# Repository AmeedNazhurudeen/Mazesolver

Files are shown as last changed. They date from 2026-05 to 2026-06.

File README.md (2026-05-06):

# 🐭 Micromouse Maze Solver Robot

An autonomous micromouse robot designed to solve unknown mazes using real-time mapping, flood fill path planning, and sensor-based closed-loop control.

This project focuses on **embedded robotics, motion control, and intelligent path planning under real-world constraints**.

---

## 🚀 Project Goals

- Explore unknown 16×16 maze environments
- Build an internal map in real-time
- Compute shortest path to the goal cell
- Execute high-speed optimized runs
- Maintain stable motion using PID control

---

## ⚙️ Hardware Overview

- **Microcontroller:** Teensy 2.0 (upgradeable to Teensy 4.0)
- **Motors:** N20 DC motors with encoders
- **Motor Driver:** TB6612FNG / DRV8833 (recommended upgrade)
- **Distance Sensors:** VL53L0X ToF sensors (x3)
- **IMU:** MPU6050 (gyro + accelerometer)
- **Power:** LiPo battery (7.4V recommended)

---

## 🧠 Core System Architecture

The robot is designed as a layered embedded system:

Sensors → Perception → Mapping → Decision → Motion → Control

### Layers:

- **Sensor Layer:** IR / ToF / Encoder / IMU readings
- **Perception Layer:** Wall detection & distance estimation
- **Mapping Layer:** Maze grid construction
- **Decision Layer:** Flood Fill path planning
- **Motion Layer:** Speed profile & turn execution
- **Control Layer:** PID motor control

---

## 🧭 Algorithms Used

### 1. Flood Fill Algorithm (Main Navigation)

Each maze cell is assigned a distance value relative to the goal. The robot always moves toward the lowest-cost neighboring cell.

This ensures:
- Guaranteed shortest path (after full exploration)
- Dynamic adaptation to discovered walls
- Real-time re-planning capability

---

### 2. PID Control System

Used for:
- Wall following stability
- Speed control
- Smooth turning

Inputs:
- Encoder feedback
- IR sensor error

---

### 3. State Machine

The robot operates in two main modes:

- **EXPLORATION MODE**
  - Builds maze map
  - Updates flood fill values dynamically

- **SPEED RUN MODE**
  - Executes optimized shortest path
  - Focuses on maximum speed and stability

---

## 📡 Sensor Strategy

### Primary Sensors:
- IR sensors → real-time wall detection (fast control loop)

### Secondary Sensors:
- VL53L0X ToF → distance estimation & mapping support
- MPU6050 IMU → turning stability and angular correction
- Encoders → precise movement tracking

---

## ⚡ Motion Strategy

- Trapezoidal velocity profile (accelerate → cruise → decelerate)
- Corner smoothing for faster turns
- Straight-line optimization during speed run phase

---

## 🧱 Key Features

- Real-time maze mapping
- Adaptive flood fill path planning
- Sensor fusion-based navigation
- Closed-loop PID motor control
- Exploration + speed run mode switching

---

## 🛠️ Folder Structure

micromouse-maze-solver/
│
├── firmware/ # Embedded robot code
├── hardware/ # PCB, wiring, BOM
├── simulation/ # Maze simulation tools
├── docs/ # Architecture & technical docs
├── tools/ # Calibration & debugging scripts
└── tests/ # Unit tests for algorithms

---

## 📈 Future Improvements

- Upgrade to high-speed microcontroller (Teensy 4.0 / STM32)
- Replace or complement ToF with high-speed IR arrays
- Implement A* hybrid optimization for faster path computation
- Add SLAM-based mapping for advanced research applications
- Improve motion planning using S-curve velocity profiles

---

## 🎯 Applications

- Micromouse robotics competitions
- Autonomous navigation research
- Embedded systems optimization
- Path planning algorithm benchmarking
- Mobile robotics research projects

---

## 🧪 Status

🚧 In Development  
✔ Hardware design ongoing  
✔ Algorithm implementation in progress  
✔ Simulation layer planned  

---

## 📜 License

This project is open-source for educational and research purposes.

---

## 🤖 Author

Built as part of an advanced robotics learning and competition project focused on autonomous navigation systems and embedded intelligence.

---

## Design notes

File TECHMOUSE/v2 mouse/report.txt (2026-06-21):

Info: Output directory '/Users/ameednazhurudeen/Downloads/SONIC MOUSE V3' created.
Plotted to '/Users/ameednazhurudeen/Downloads/SONIC MOUSE V3/v2 mouse-F_Cu.gbr'.
Plotted to '/Users/ameednazhurudeen/Downloads/SONIC MOUSE V3/v2 mouse-B_Cu.gbr'.
Plotted to '/Users/ameednazhurudeen/Downloads/SONIC MOUSE V3/v2 mouse-F_Silkscreen.gbr'.
Plotted to '/Users/ameednazhurudeen/Downloads/SONIC MOUSE V3/v2 mouse-B_Silkscreen.gbr'.
Plotted to '/Users/ameednazhurudeen/Downloads/SONIC MOUSE V3/v2 mouse-F_Mask.gbr'.
Plotted to '/Users/ameednazhurudeen/Downloads/SONIC MOUSE V3/v2 mouse-B_Mask.gbr'.
Plotted to '/Users/ameednazhurudeen/Downloads/SONIC MOUSE V3/v2 mouse-Edge_Cuts.gbr'.
Created Gerber job file '/Users/ameednazhurudeen/Downloads/SONIC MOUSE V3/v2 mouse-job.gbrjob'.
Info: Done.
Info: Done.

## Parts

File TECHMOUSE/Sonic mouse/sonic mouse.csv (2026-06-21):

Reference | Qty | Value | DNP | Exclude from BOM | Exclude from Board | Footprint | Datasheet
ACC1 | 1 | GY-521 |  |  |  | GY-521:GY-521
C1,C2,C3,C4,C5,C6 | 6 | EEUFR1E101 |  |  |  | EEUFR1E101:CAPPRD250W50D630H1120
C7,C9 | 2 | C_Small |  |  |  | ceramic:C320C | ~
D1 | 1 | LED |  |  |  | LED_THT:LED_D3.0mm_Horizontal_O1.27mm_Z6.0mm | ~
D3 | 1 | LED D2 |  |  |  | LED_THT:LED_D3.0mm_Horizontal_O1.27mm_Z6.0mm | ~
J1 | 1 | B2B-XH-A_LF__SN_ |  |  |  | Connector_JST:JST_EH_B2B-EH-A_1x02_P2.50mm_Vertical
J2 | 1 | Motor 1 |  |  |  | Connector_JST:JST_PH_B2B-PH-K_1x02_P2.00mm_Vertical
J3 | 1 | Motor 2 |  |  |  | Connector_JST:JST_PH_B2B-PH-K_1x02_P2.00mm_Vertical
J4 | 1 | Conn_01x06_Socket |  |  |  | Connector_PinSocket_1.27mm:PinSocket_1x06_P1.27mm_Vertical | ~
R1,R2,R3,R4 | 4 | 220 |  |  |  | Resistor_THT:R_Axial_DIN0204_L3.6mm_D1.6mm_P1.90mm_Vertical | ~
R5,R6,R7,R11 | 4 | 10 |  |  |  | Resistor_THT:R_Axial_DIN0204_L3.6mm_D1.6mm_P1.90mm_Vertical | ~
R9,R10 | 2 | 330 |  |  |  | Resistor_THT:R_Axial_DIN0204_L3.6mm_D1.6mm_P1.90mm_Vertical | ~
S1,S2 | 2 | FSM8JH |  |  |  | FSM8JH:SW_FSM8JH
U1 | 1 | AMS1117-5.0 |  |  |  | AMS1117-5.0:SOT229P700X180-4N
U2 | 1 | AMS1117-3.3 |  |  |  | AMS1117-3.3:SOT229P700X180-4N
U3 | 1 | DEV-15583 |  |  |  | DEV-15583 (2):MODULE_DEV-15583
U4 | 1 | ROB-14450 |  |  |  | ROB-14450:MODULE_ROB-14450
U5,U6,U7,U8 | 4 | TCRT5000 |  |  |  | TCRT5000 (1):OPTO_TCRT5000

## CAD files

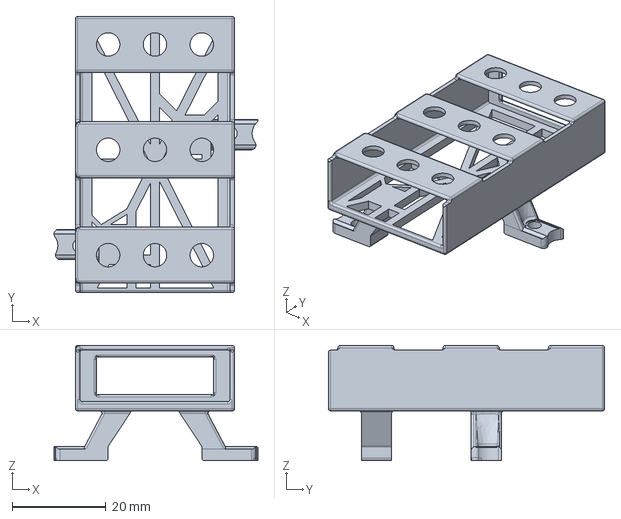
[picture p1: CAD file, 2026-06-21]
design files/Battery holder.step
43.6 x 59.0 x 24.6 mm

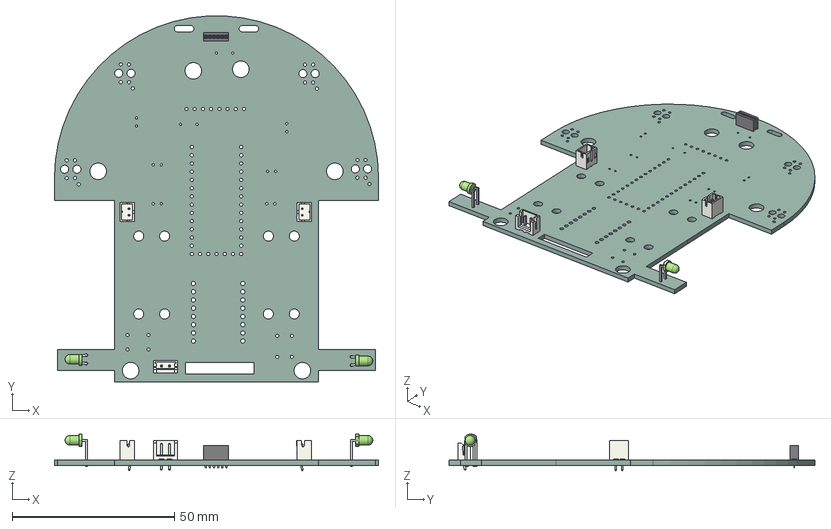
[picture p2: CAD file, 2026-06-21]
TECHMOUSE/v2 mouse/v2 mouse.step
100.0 x 112.9 x 11.3 mm
LED_D3.0mm_Horizontal_O1.27mm_Z6.0mm x 2
PinSocket_1x06_P1.27mm_Vertical
JST_EH_B2B-EH-A_1x02_P2.50mm_Vertical
JST_PH_B2B-PH-K_1x02_P2.00mm_Vertical x 2
v2 mouse_PCB

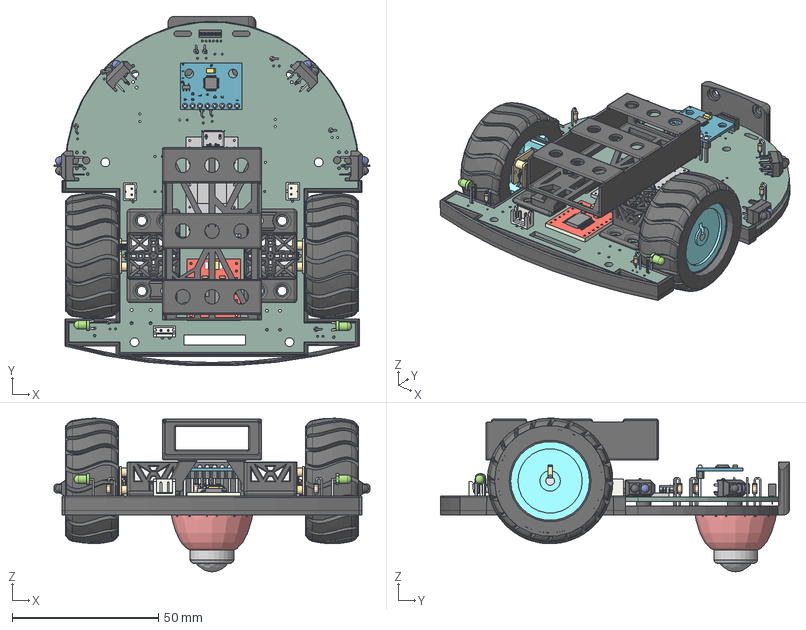
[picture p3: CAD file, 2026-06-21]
design files/Maze Solver .step
108.1 x 119.5 x 52.6 mm
R_Axial_DIN0204_L3.6mm_D1.6mm_P1.90mm_Vertical x 10
LED_D3.0mm_Horizontal_O1.27mm_Z6.0mm x 2
PinSocket_1x06_P1.27mm_Vertical
JST_EH_B2B-EH-A_1x02_P2.50mm_Vertical
JST_PH_B2B-PH-K_1x02_P2.00mm_Vertical x 2
v2 mouse_PCB
clamp x 2
Teensy_4.0_PCB
Micro USB-B Female 5Pin SMD
NXP iMXRT1062
SKRPACE010 v4
TB6612FNG_No Pins
Gear Box x 2
Shaft x 2
Motor x 2
Y
Clone_of_Array
Clone_of_Clone_of_Array
Clone_of_Clone_of_Array001
VCC
GND
SCL
SDA
XDA
XCL
AD0
INT
BotNakama
MPU_1
Cubo001
X
TCRT-5000-modelado x 2
TCRT-5000-modelado v1(Mirror) x 2
Housing x 2
Ball Caster Wheel

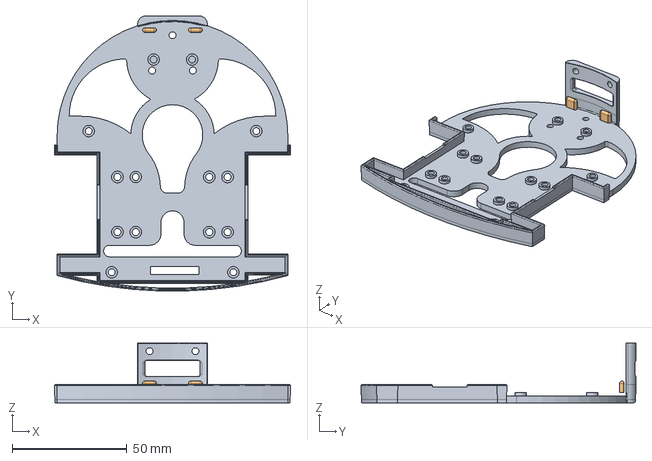
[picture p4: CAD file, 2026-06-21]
design files/Base Frame.step
102.8 x 119.8 x 26.0 mm

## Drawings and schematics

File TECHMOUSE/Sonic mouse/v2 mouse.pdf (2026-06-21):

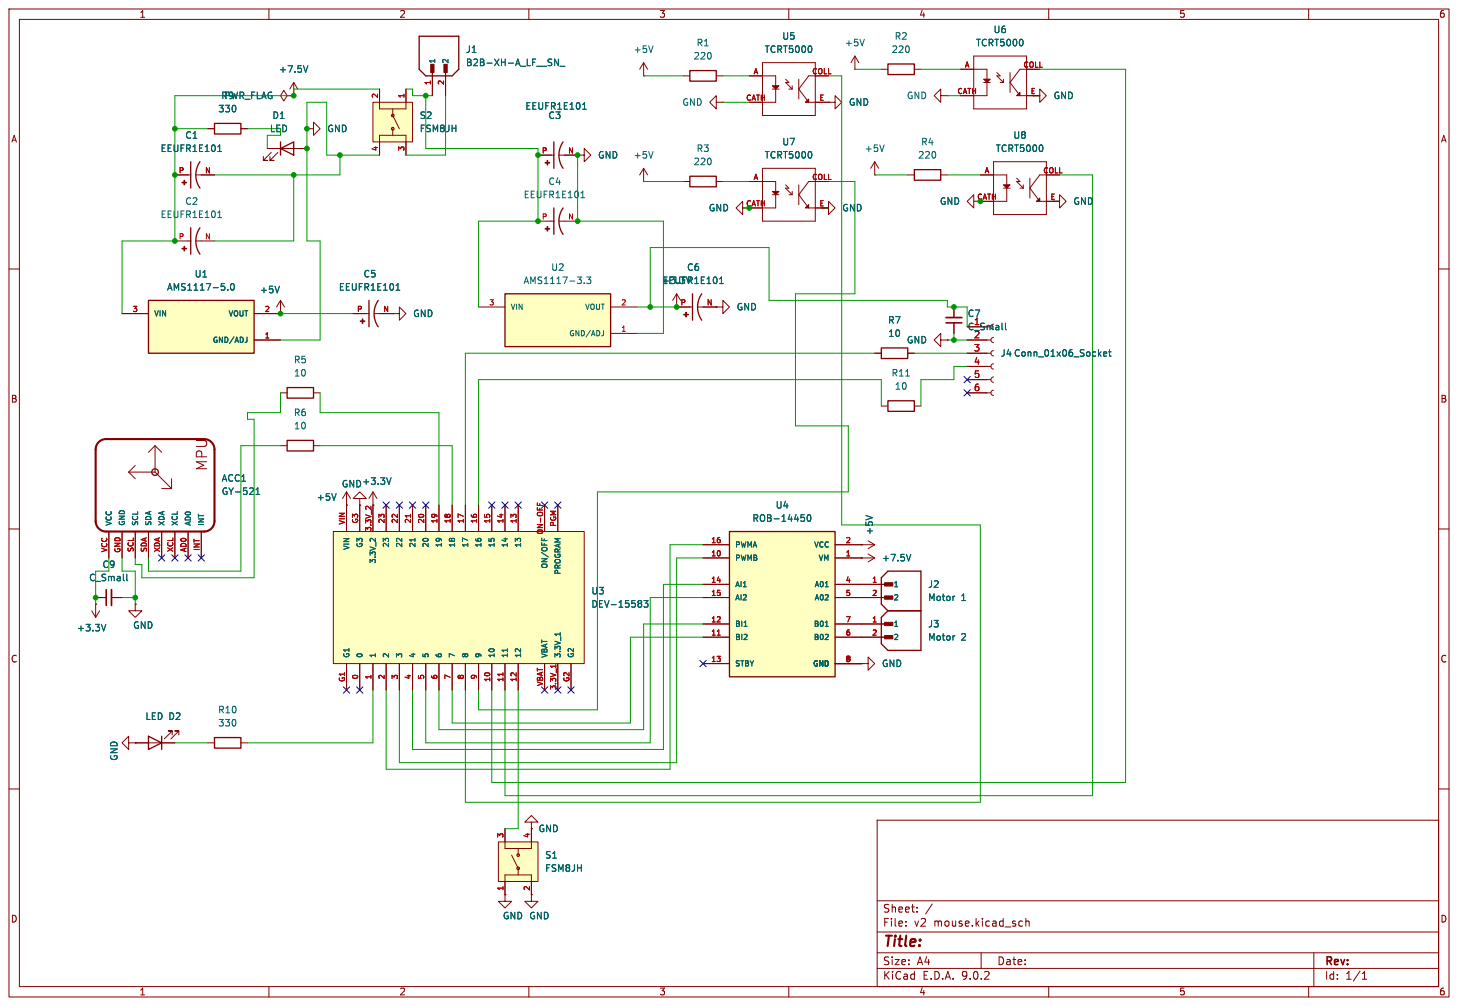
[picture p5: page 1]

9 10 10 11 11 12 12 VBAT VBAT 3.3V_1 3.3V_1 G2 G2 VIN VIN G3 G3 3.3V_2 3.3V_2 23 23 22 22 21 21 20 20 19 19 18 18 17 17 16 16 15 15 14 14 13 13 ON/OFF ON-OFF PROGRAM PGM U3 DEV-15583

9 10 10 11 11 12 12 VBAT VBAT 3.3V_1 3.3V_1 G2 G2 VIN VIN G3 G3 3.3V_2 3.3V_2 23 23 22 22 21 21 20 20 19 19 18 18 17 17 16 16 15 15 14 14 13 13 ON/OFF ON-OFF PROGRAM PGM GNDGND GND

Id: 1/1 Title: File: v2 mouse.kicad_sch Sheet: /

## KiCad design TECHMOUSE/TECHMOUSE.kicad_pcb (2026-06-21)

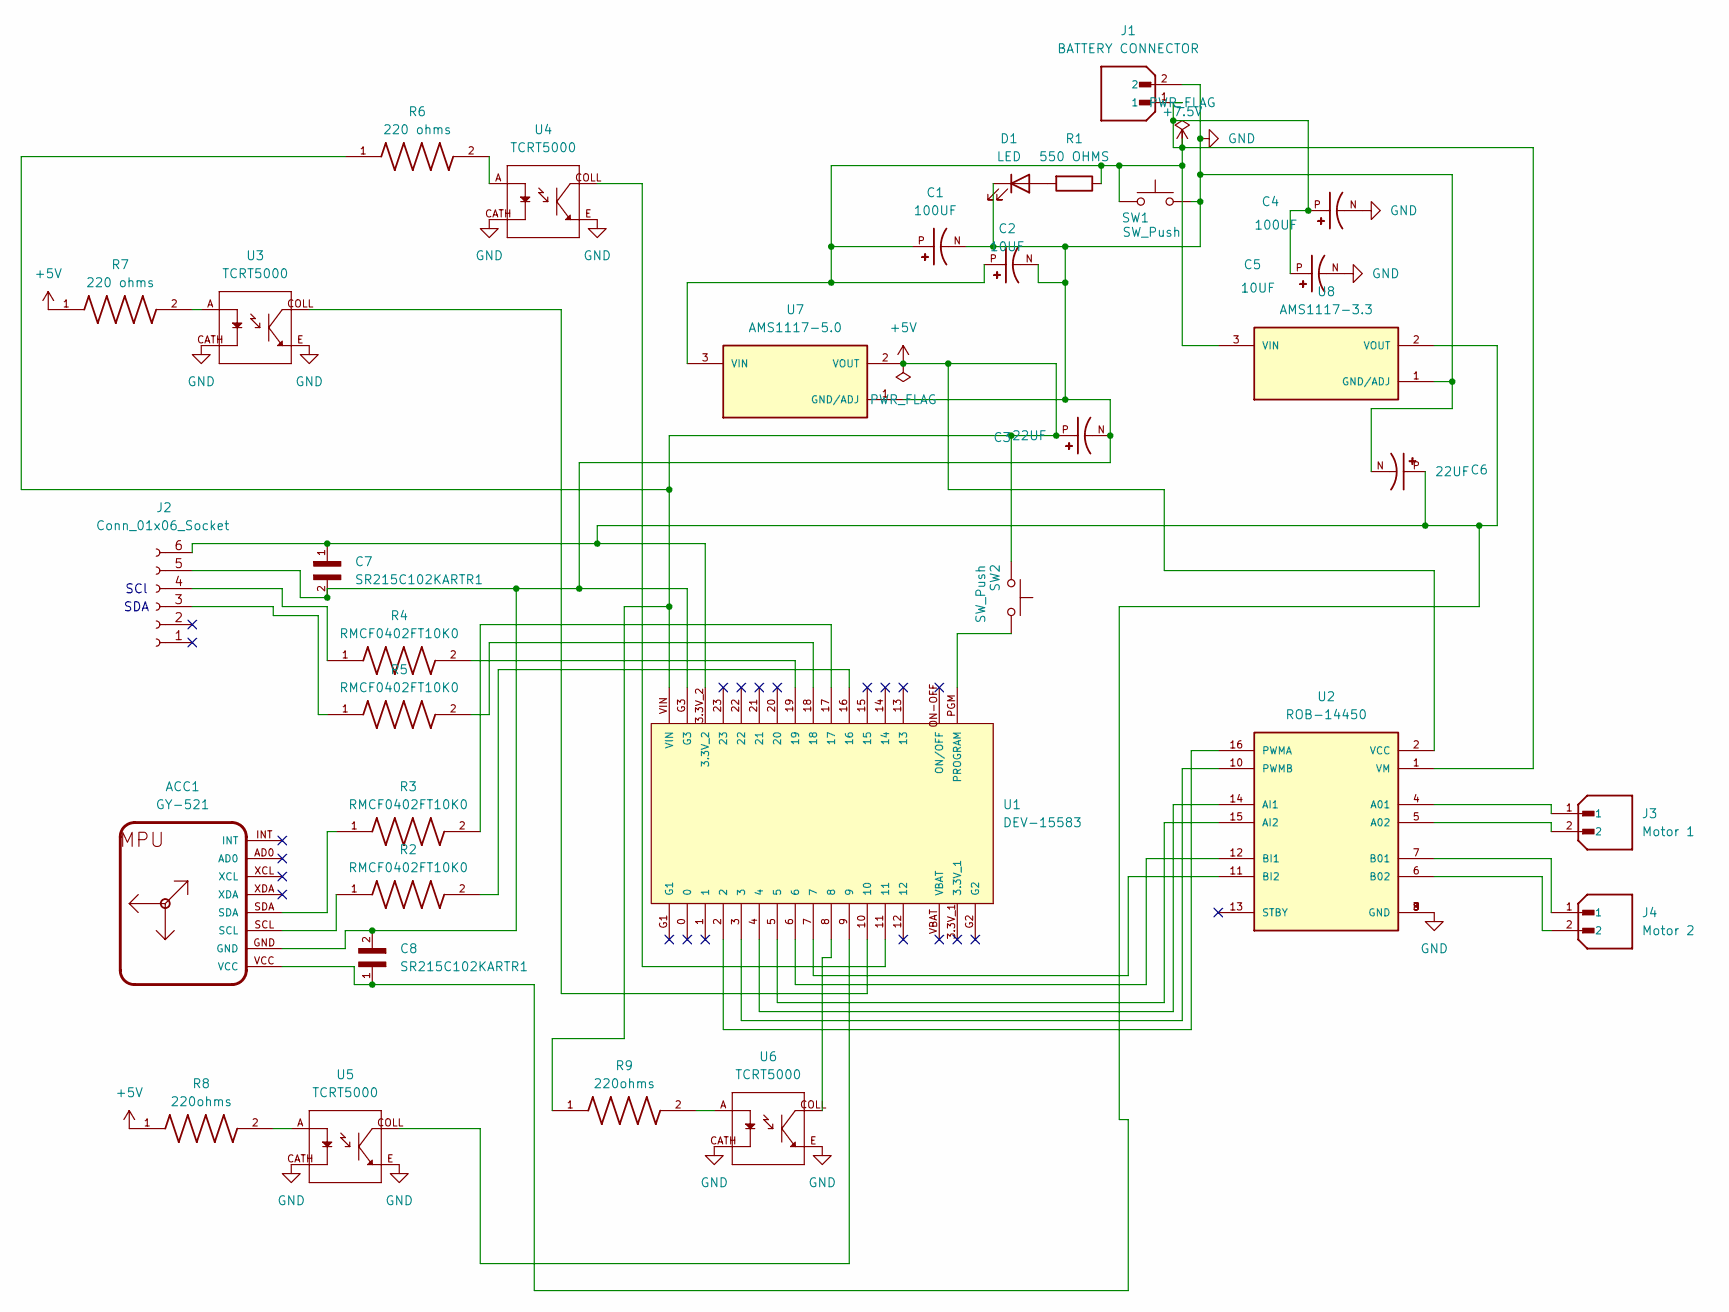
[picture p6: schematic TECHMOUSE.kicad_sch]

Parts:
ACC1: GY-521
C1, C4: 100UF; CAPPRD250W50D630H1120; PARTREV 28-FEB-20
C2, C5: 10UF; CAPPRD250W50D630H1120; PARTREV 28-FEB-20
C3, C6: 22UF; CAPPRD250W50D630H1120; PARTREV 28-FEB-20
C7, C8: SR215C102KARTR1; CAPRR508W50L508T317H508; PARTREV 081816
D1: LED; LED_D1.8mm_W1.8mm_H2.4mm_Horizontal_O1.27mm_Z8.2mm
J1: BATTERY CONNECTOR; JST_EH_B2B-EH-A_1x02_P2.50mm_Vertical; PARTREV N/A
J2: Conn_01x06_Socket; PinSocket_1x06_P1.27mm_Vertical
J3: Motor 1; JST_EH_B2B-EH-A_1x02_P2.50mm_Vertical; PARTREV N/A
J4: Motor 2; JST_EH_B2B-EH-A_1x02_P2.50mm_Vertical; PARTREV N/A
R1: 550 OHMS; R_Axial_DIN0204_L3.6mm_D1.6mm_P5.08mm_Horizontal
R2, R3, R4, R5: RMCF0402FT10K0; RESC1005X40
R6, R7: 220 ohms; RESC1005X35N
R8, R9: 220ohms; RESC1005X35N
SW1, SW2: SW_Push; SW_PUSH_6mm
U1: DEV-15583; MODULE_DEV-15583
U2: ROB-14450; MODULE_ROB-14450; PARTREV 11-13-17
U3, U4, U5, U6: TCRT5000; OPTO_TCRT5000; PARTREV 1.7
U7: AMS1117-5.0; SOT229P700X180-4N; PARTREV N/A
U8: AMS1117-3.3; SOT229P700X180-4N; PARTREV N/A

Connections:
+5V: C3.P, R6.1, R7.1, R8.1, R9.1, SW2.1, U1.VIN, U2.2 (VCC), U7.2 (VOUT)
+7.5V: C1.P, C2.P, C4.P, C5.P, J1.1, R1.1, SW1.1, U2.1 (VM), U7.3 (VIN), U8.3 (VIN)
GND: ACC1.GND, C1.N, C2.N, C3.N, C4.N, C5.N, C6.N, C7.2, C8.2, D1.1 (K), J1.2, J2.5, SW1.2, U1.G3, U2.3 (GND), U2.8 (GND), U2.9 (GND), U3.CATH, U3.E, U4.CATH, U4.E, U5.CATH, U5.E, U6.CATH, U6.E, U7.1 (GND/ADJ), U8.1 (GND/ADJ)
unnamed: ACC1.SCL, R2.1
unnamed: ACC1.SDA, R3.1
unnamed: D1.2 (A), R1.2
unnamed: J2.3, R5.1
unnamed: J2.4, R4.1
unnamed: ACC1.VCC, C6.P, C7.1, C8.1, J2.6, U1.3.3V_2, U8.2 (VOUT)
unnamed: R2.2, U1.16
unnamed: R3.2, U1.17
unnamed: R4.2, U1.19
unnamed: R5.2, U1.18
unnamed: R6.2, U4.A
unnamed: R7.2, U3.A
unnamed: R8.2, U5.A
unnamed: R9.2, U6.A
unnamed: SW2.2, U1.PGM (PROGRAM)
unnamed: U1.8, U6.COLL
unnamed: U1.9, U5.COLL
unnamed: U1.10, U3.COLL
unnamed: U1.11, U4.COLL
unnamed: J3.1, U2.4 (A01)
unnamed: J3.2, U2.5 (A02)
unnamed: U1.4, U2.14 (AI1)
unnamed: U1.5, U2.15 (AI2)
unnamed: J4.1, U2.7 (B01)
unnamed: J4.2, U2.6 (B02)
unnamed: U1.6, U2.12 (BI1)
unnamed: U1.7, U2.11 (BI2)
unnamed: U1.2, U2.16 (PWMA)
unnamed: U1.3, U2.10 (PWMB)

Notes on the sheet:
SDA
SCl

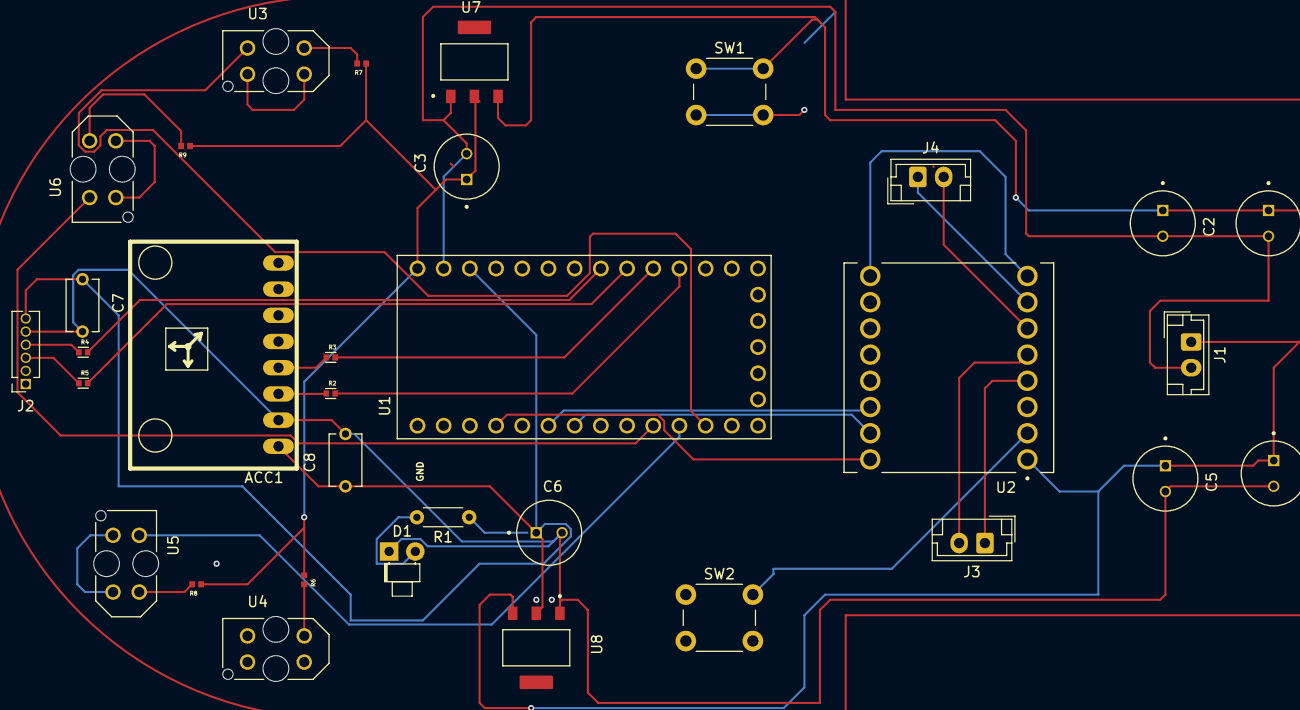
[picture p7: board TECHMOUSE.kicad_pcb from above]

Board: 2 copper layers, 33 parts (0 on the bottom side), 32 nets.

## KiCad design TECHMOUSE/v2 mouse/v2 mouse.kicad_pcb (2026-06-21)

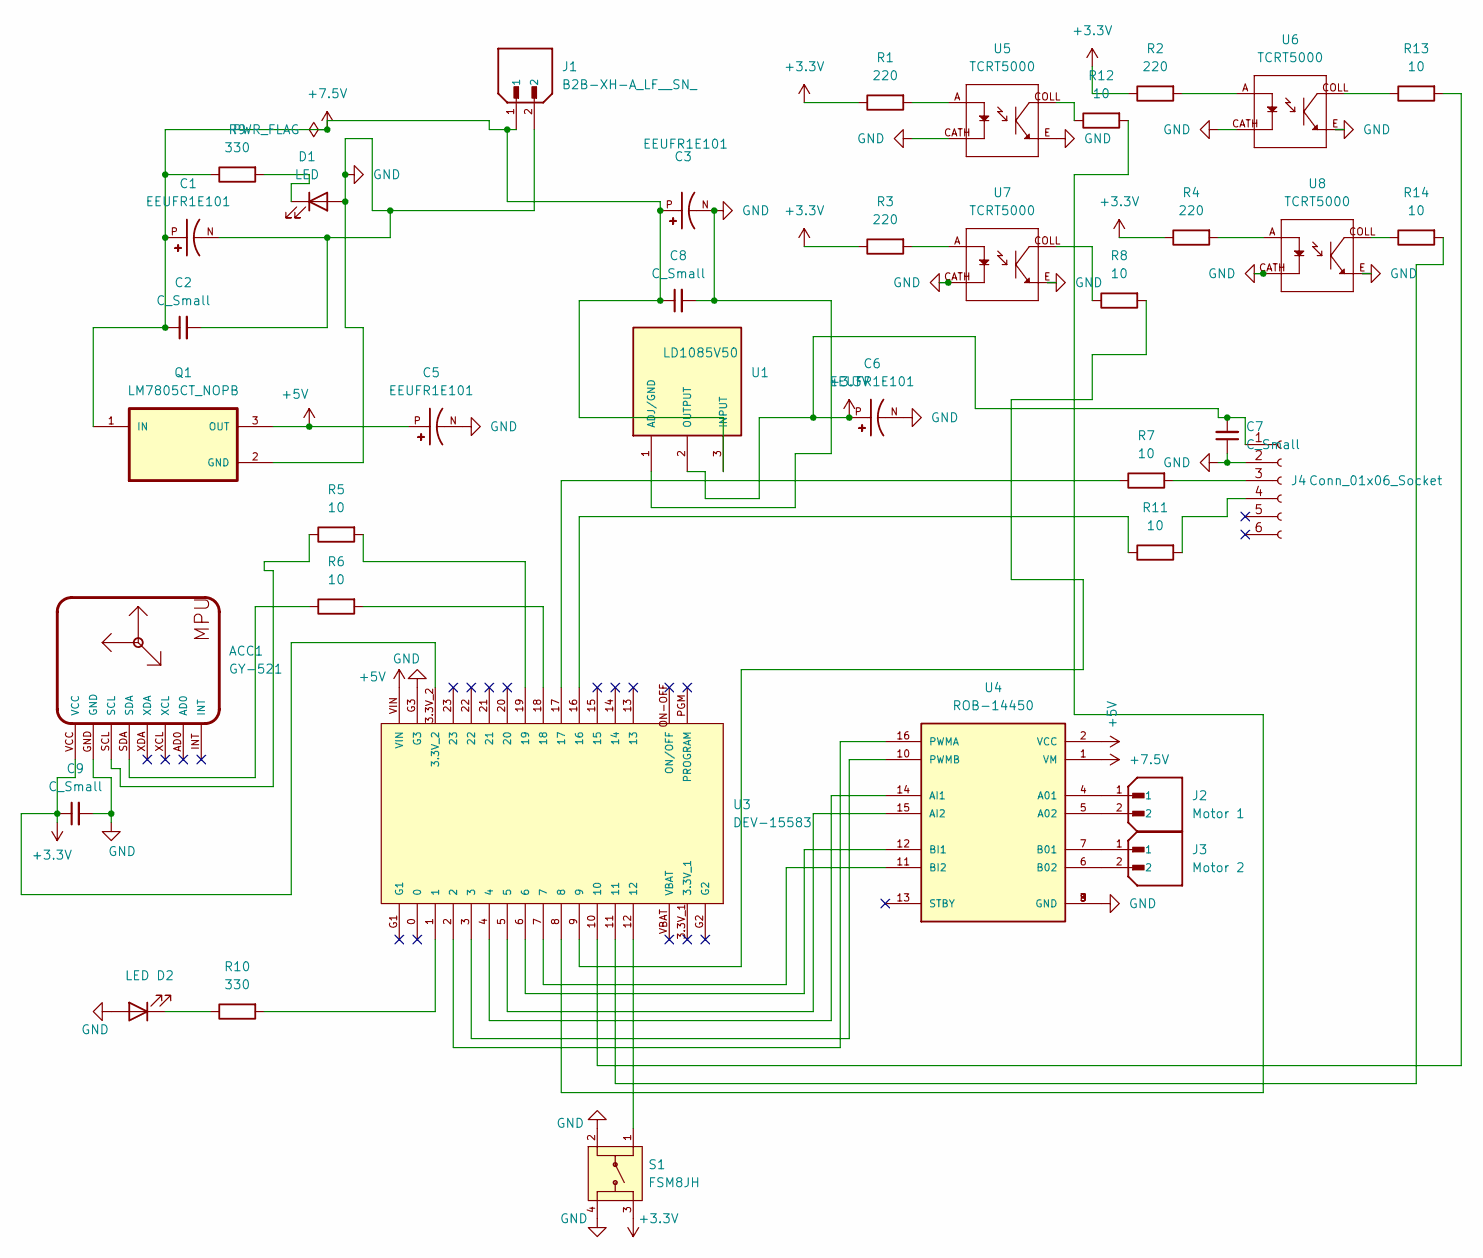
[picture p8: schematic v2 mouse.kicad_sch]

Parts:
ACC1: GY-521
C1, C3, C5, C6: EEUFR1E101; CAPPRD250W50D630H1120; PARTREV 28-FEB-20
C2, C7, C8, C9: C_Small; C320C
D1: LED; LED_D3.0mm_Horizontal_O1.27mm_Z6.0mm
D3: LED D2; LED_D3.0mm_Horizontal_O1.27mm_Z6.0mm
J1: B2B-XH-A_LF__SN_; JST_EH_B2B-EH-A_1x02_P2.50mm_Vertical; PARTREV N/A
J2: Motor 1; JST_PH_B2B-PH-K_1x02_P2.00mm_Vertical; PARTREV N/A
J3: Motor 2; JST_PH_B2B-PH-K_1x02_P2.00mm_Vertical; PARTREV N/A
J4: Conn_01x06_Socket; PinSocket_1x06_P1.27mm_Vertical
Q1: LM7805CT_NOPB; TO220; PARTREV LTR
R1, R2, R3, R4: 220; R_Axial_DIN0204_L3.6mm_D1.6mm_P1.90mm_Vertical
R5, R6, R7, R8, R11, R12, R13, R14: 10; R_Axial_DIN0204_L3.6mm_D1.6mm_P1.90mm_Vertical
R9, R10: 330; R_Axial_DIN0204_L3.6mm_D1.6mm_P1.90mm_Vertical
S1: FSM8JH; SW_FSM8JH; PARTREV C10
U1: LD1085V50; TO220
U3: DEV-15583; MODULE_DEV-15583
U4: ROB-14450; MODULE_ROB-14450; PARTREV 11-13-17
U5, U6, U7, U8: TCRT5000; OPTO_TCRT5000; PARTREV 1.7

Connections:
+3.3V: ACC1.VCC, C6.P, C7.2, C9.1, J4.1, R1.1, R2.1, R3.1, R4.1, S1.3, U1.2 (OUTPUT), U3.3.3V_2
+5V: C5.P, Q1.3 (OUT), U3.VIN, U4.2 (VCC)
+7.5V: C1.P, C2.1, C3.P, C8.1, J1.1, Q1.1 (IN), R9.1, U1.3 (INPUT), U4.1 (VM)
GND: ACC1.GND, C1.N, C2.2, C3.N, C5.N, C6.N, C7.1, C8.2, C9.2, D1.2 (A), D3.2 (A), J1.2, J4.2, Q1.2 (GND), S1.2, S1.4, U1.1 (ADJ/GND), U3.G3, U4.3 (GND), U4.8 (GND), U4.9 (GND), U5.CATH, U5.E, U6.CATH, U6.E, U7.CATH, U7.E, U8.CATH, U8.E
unnamed: ACC1.SCL, R5.1
unnamed: ACC1.SDA, R6.1
unnamed: D1.1 (K), R9.2
unnamed: D3.1 (K), R10.1
unnamed: J4.3, R7.2
unnamed: J4.4, R11.2
unnamed: R1.2, U5.A
unnamed: R2.2, U6.A
unnamed: R3.2, U7.A
unnamed: R4.2, U8.A
unnamed: R5.2, U3.19
unnamed: R6.2, U3.18
unnamed: R7.1, U3.17
unnamed: R8.1, U7.COLL
unnamed: R8.2, U3.9
unnamed: R10.2, U3.1
unnamed: R11.1, U3.16
unnamed: R12.1, U5.COLL
unnamed: R12.2, U3.8
unnamed: R13.1, U6.COLL
unnamed: R13.2, U3.10
unnamed: R14.1, U8.COLL
unnamed: R14.2, U3.11
unnamed: S1.1, U3.12
unnamed: J2.1, U4.4 (A01)
unnamed: J2.2, U4.5 (A02)
unnamed: U3.4, U4.14 (AI1)
unnamed: U3.5, U4.15 (AI2)
unnamed: J3.1, U4.7 (B01)
unnamed: J3.2, U4.6 (B02)
unnamed: U3.6, U4.12 (BI1)
unnamed: U3.7, U4.11 (BI2)
unnamed: U3.2, U4.16 (PWMA)
unnamed: U3.3, U4.10 (PWMB)

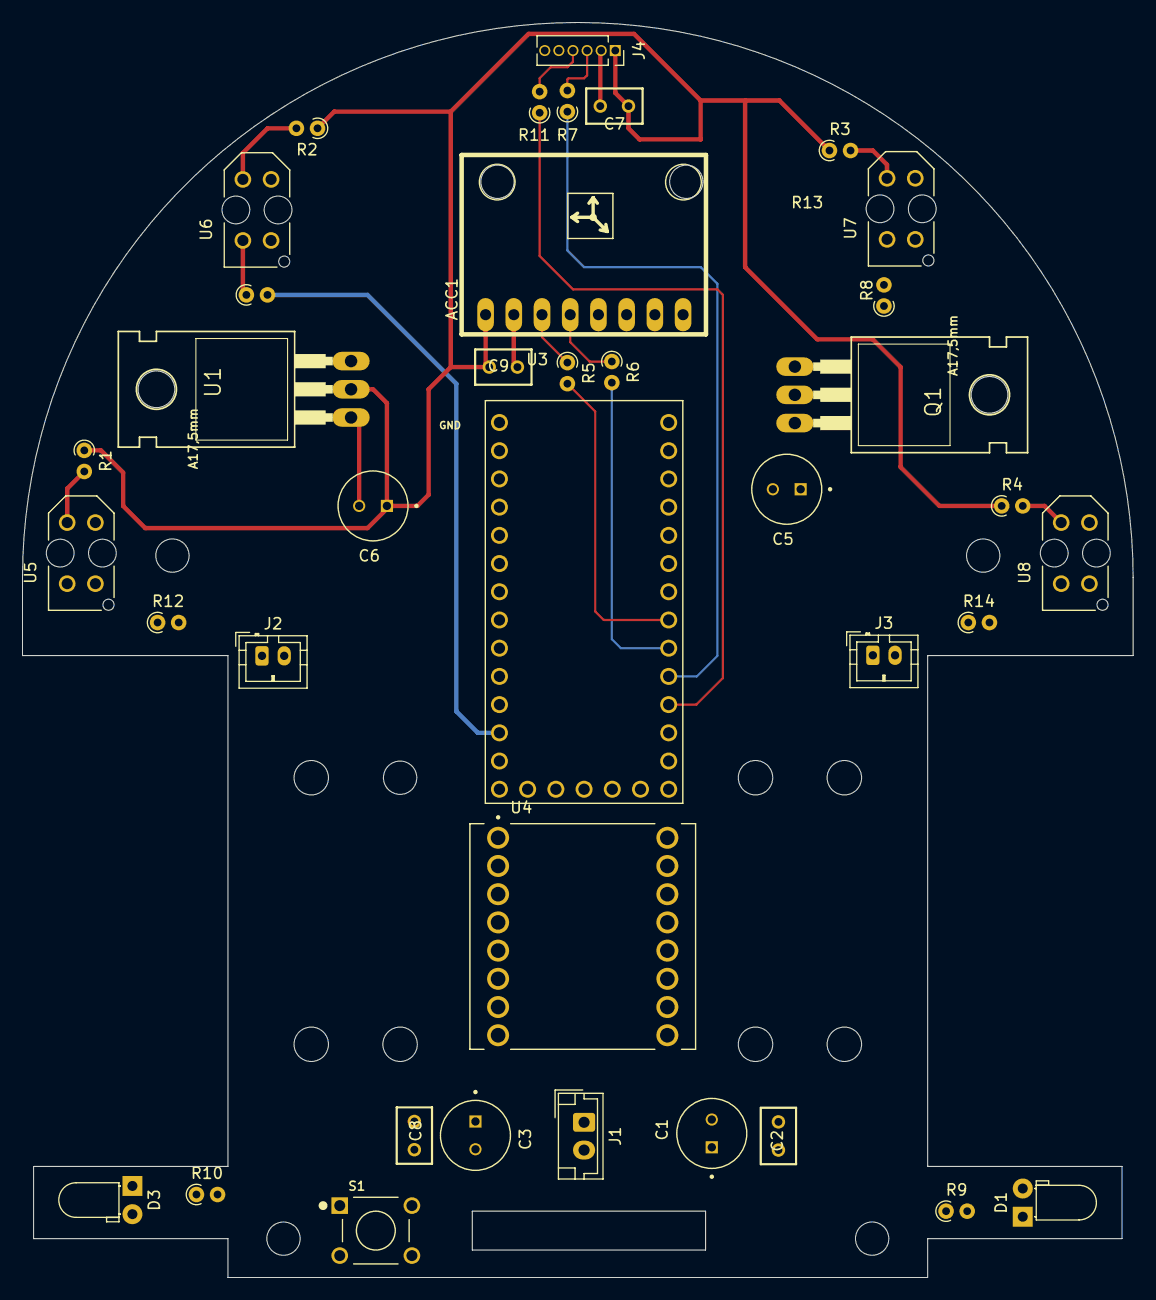
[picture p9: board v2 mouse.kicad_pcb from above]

Board: 2 copper layers, 100.0 x 113.0 mm, 38 parts (0 on the bottom side), 38 nets.
